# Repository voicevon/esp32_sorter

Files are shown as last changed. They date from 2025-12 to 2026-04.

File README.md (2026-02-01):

# ESP32 Sorter 项目

这是一个基于ESP32开发的物料分拣系统，使用PlatformIO和Arduino框架开发。系统主要用于传输线上的物料分拣，通过直径数据对物料进行分类，并使用舵机控制的出口将物料分配到不同通道。

## 项目功能

- 31个传输线托盘的环形管理系统
- 8个出口舵机控制（用于物料分配）
- 4点激光扫描仪直径数据接收和处理
- 基于物料直径的智能分类算法（使用中位数算法）
- 编码器相位触发的采样和控制
- 多种诊断模式支持
- 上料器控制功能
- 串口调试日志输出

## 项目架构

- **Sorter**：系统主控协调器，协调各组件工作
- **TraySystem**：管理所有托盘的状态和移动
- **Encoder**：编码器类，提供位置跟踪和中断处理
- **Outlet**：单个出口的控制
- **SimpleHMI**：人机交互模块，处理按钮和LED
- **DiameterScanner**：直径扫描仪类，处理激光扫描数据

## 目录结构

```
d:\Firmware\esp32_sorter\
├── .trae/              # 项目规则目录
│   └── rules/
│       └── project_rules.md
├── doc/                # 文档目录
│   ├── Hardware_Reference.md     # 硬件参考手册
│   ├── Software_Architecture.md  # 软件架构手册
│   ├── Operation_Guide.md        # 操作指南
│   └── Refactoring_Notes.md      # 重构笔记
├── src/                # 源代码目录
│   ├── main.cpp           # 主程序入口
│   ├── sorter.cpp         # 系统主控协调器实现
│   ├── sorter.h           # 系统主控协调器头文件
│   ├── tray_system.cpp    # 传输系统实现
│   ├── tray_system.h      # 传输系统头文件
│   ├── outlet.h           # 出口控制头文件
│   ├── encoder.cpp        # 编码器实现
│   ├── encoder.h          # 编码器头文件
│   ├── simple_hmi.cpp     # 人机交互模块实现
│   ├── simple_hmi.h       # 人机交互模块头文件
│   ├── diameter_scanner.cpp # 直径扫描仪实现
│   ├── diameter_scanner.h   # 直径扫描仪头文件
│   └── pins.h             # 引脚定义文件
├── .gitignore           # Git忽略文件
├── CMakeLists.txt       # CMake配置文件
├── README.md            # 项目说明文档
├── platformio.ini       # PlatformIO配置文件
```

## 文档索引

更详细的系统文档请参考 `doc/` 目录下的手册：

- **[硬件参考](doc/Hardware_Reference.md)**: 包含硬件组件说明、引脚定义、编码器和扫描仪原理。
- **[软件架构](doc/Software_Architecture.md)**: 包含系统核心逻辑、类结构、分拣规则和时序控制。
- **[操作指南](doc/Operation_Guide.md)**: 包含系统模式、菜单操作、诊断模式使用说明。
- **[重构笔记](doc/Refactoring_Notes.md)**: 代码优化和重构建议。

## 环境搭建

### VS Code + PlatformIO插件（推荐）

1. 安装VS Code
2. 安装PlatformIO插件
3. 打开项目目录 `d:/Firmware/esp32_sorter`
4. PlatformIO会自动识别项目并加载相关配置

### USB驱动安装

ESP32开发板通常使用CP210x、CH340或FTDI芯片作为USB转串口芯片，需要安装相应驱动。

## 编译和烧录

### 使用VS Code + PlatformIO插件

1. **构建项目**：点击VS Code底部状态栏中的 ✓ 图标或按F7键
2. **烧录项目**：点击底部状态栏中的 → 图标或按Ctrl+Alt+U键
3. **监控串口**：点击底部状态栏中的 🔌 图标或按Ctrl+Alt+S键

### 使用命令行

```bash
# 构建项目
C:\Users\feng\.platformio\penv\Scripts\platformio.exe run

# 烧录项目
C:\Users\feng\.platformio\penv\Scripts\platformio.exe run -t upload
```

## 系统模式

系统支持多种工作模式：

- **MODE_NORMAL**：正常工作模式
- **MODE_DIAGNOSE_ENCODER**：诊断编码器模式
- **MODE_DIAGNOSE_SCANNER**：诊断扫描仪模式
- **MODE_DIAGNOSE_OUTLET**：诊断出口模式
- **MODE_DIAGNOSE_CONVEYOR**：诊断传输线模式
- **MODE_TEST**：测试模式
- **MODE_TEST_RELOADER**：上料器测试模式

使用主按钮可以切换不同的工作模式。

## 代码风格规范

- 使用4个空格进行缩进
- 花括号使用K&R风格
- 每行不超过100个字符
- 添加必要的注释说明功能和参数
- 类和函数使用驼峰命名法
- 常量使用全大写和下划线

## 调试

- 使用Serial.println()进行基本调试
- 禁止使用JTAG调试器进行调试

## 常见问题解决

- **端口错误**：确保在platformio.ini中正确设置了COM端口
- **烧录失败**：检查ESP32开发板连接，某些开发板可能需要在烧录时按住BOOT键
- **编译错误**：确保PlatformIO已正确安装，检查代码语法

## 注意事项

- 系统仅使用串口进行数据输出（调试日志），不会从外部接收串口命令
- 系统控制通过诊断控制器按钮实现
- 编码器使用AB相双中断模式和四状态解码算法
- 禁止创建和使用Tray、TrayManager、OutletController类

## 故障排除

- 如果构建失败，请检查代码语法和依赖库
- 如果上传失败，请确认COM端口配置和USB连接
- 如果系统运行异常，可以通过串口监视器查看调试信息

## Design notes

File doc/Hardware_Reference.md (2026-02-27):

# ESP32 Sorter 硬件参考手册

本文档提供了ESP32分拣系统硬件组件的参考说明。

---

## 1. 系统硬件概述

### 1.1 硬件组件

- **主编码器模块 (Encoder)**：增量式编码器，用于位置检测。
- **RS485接口**：用于与外部系统进行通信。
- **点扫描仪 (Point Scanner)**：5点扫描仪阵列，用于物体检测。
- **舵机 (Servo)**：2个控制舵机，不控制出口，专门用于**上料器 (Feeder) / 上送料器**。
- **电位器 (Potentiometer)**：ADC模拟输入，用于调节外部伺服电机的速度（伺服电机通过RS485 Modbus通信）。
- **电磁铁 (Solenoid)**：8个 12V 供电的电磁铁，用于控制出口分流，通过 HC595 移位寄存器控制。
- **HC595 移位寄存器**：3个 74HC595 级联，用于扩展输出。其中 Index 0（离MCU最近）的一组用于驱动8个状态指示 LED，其余用于驱动 12V 电磁铁。
- **电源电压监测**：用于监测系统工作电压。
- **HMI模块**：1个带按钮的旋转编码器，用于人机交互。包含A相、B相和按键。
- **显示器 (Display)**：I2C OLED显示器。

### 1.2 引脚连接表

| 硬件组件 | ESP32引脚 | 功能说明 |
|---|---|---|
| 编码器A相 | GPIO 19 | A相输入信号 |
| 编码器B相 | GPIO 21 | B相输入信号 |
| 编码器Z相(Zero) | GPIO 18 | 零位信号输入 |
| RS485 TX | GPIO 17 | 数据发送信号 |
| RS485 RX | GPIO 16 | 数据接收信号 |
| RS485 发送使能 | GPIO 5 | 发送使能信号 (TX Enable) |
| 扫描仪点1 | GPIO 36 (VP) | 信号输入 |
| 扫描仪点2 | GPIO 39 (VN) | 信号输入 |
| 扫描仪点3 | GPIO 34 | 信号输入 |
| 扫描仪点4 | GPIO 35 | 信号输入 |
| 扫描仪点5 | GPIO 15 | 信号输入 |
| 上料器舵机1 | GPIO 27 | PWM控制信号 |
| 上料器舵机2 | GPIO 26 | PWM控制信号 |
| 电位器输入 | GPIO 25 | ADC模拟输入，控制伺服电机速度 (RS485 Modbus) |
| HC595 数据 (DS) | GPIO 33 | SPI 数据输入 |
| HC595 时钟 (SHCP) | GPIO 4 | 移位寄存器时钟 |
| HC595 锁存 (STCP) | GPIO 2 | 存储寄存器时钟/锁存 |
| 电源电压监测 | GPIO 32 | ADC模拟输入探测电压 |
| OLED SDA | GPIO 23 | I2C数据信号 |
| OLED SCL | GPIO 22 | I2C时钟信号 |
| HMI编码器A相 | GPIO 13 | 旋转编码器A相 |
| HMI编码器B相 | GPIO 12 | 旋转编码器B相 |
| HMI编码器按键 | GPIO 14 | 旋转编码器按下 (Push/Press) |
| 串口TX0 | GPIO 1 | 调试/下载 |
| 串口RX0 | GPIO 3 | 调试/下载 |

### 1.3 引脚使用统计

| 设备类型 | 数量 | 使用引脚数 |
|---|---|---|
| 编码器 | 1 | 3 |
| RS485接口 | 1 | 3 |
| 扫描仪 | 1 | 5 |
| 上料器舵机 | 2 | 2 |
| 电位器输入 | 1 | 1 |
| HC595寄存器 | 3 | 3 |
| 电压监测 | 1 | 1 |
| OLED显示器 | 1 | 2 |
| HMI模块 | 1 | 3 |
| 串口 | 1 | 2 |
| **已分配引脚总计** | | **25个引脚** |

---

## 2. 编码器 (Encoder)

### 2.1 概述
Encoder类采用单例模式提供位置跟踪和中断处理。它追踪0-199的相位范围，用于精确的位置控制。

### 2.2 核心逻辑
- **中断**：使用AB相双中断模式和四状态解码算法，以实现高精度和抗干扰能力。
- **零位重置**：Z相中断在零位特定位置重置计数器。
- **相位回调**：当编码器相位发生变化时触发回调。

---

## 3. 直径扫描仪 (Diameter Scanner)

### 3.1 概述
DiameterScanner类处理数据采样并使用5点扫描仪阵列计算直径。

### 3.2 工作原理
1.  **采样**：同时采样5个点以测量物体直径。
2.  **加权**：对每个点应用权重系数以补偿芦笋的特定形状（锥度）：
    -   待更新...
3.  **过滤**：丢弃无效数据（小于3mm / 6个单位）。
4.  **计算**：根据有效数据数量使用基于中位数的算法。
5.  **输出**：返回以"unit"为单位的直径。实际毫米数 = unit值 / 2。

### 3.3 诊断模式
- **模式1 (IO检查)**：显示5个传感器的原始高/低电平状态。
- **模式2 (边缘校准)**：记录上升沿/下降沿的编码器值。
- **模式3 (直径测试)**：显示计算出的原始直径值。

---

## 4. 系统出口 (System Outlets)

### 4.1 概述
控制各个出口电磁铁，根据直径范围将物品分流到特定通道。不再使用舵机控制出口。

### 4.2 控制逻辑
- **初始化**：通过 HC595 寄存器设置电磁铁的状态和直径范围（最小/最大mm）。工作电压为 12V。
- **执行 (Execute)**：根据预设状态驱动相应通道的电磁铁动作。

### 4.3 测试
- **轮巡测试**...

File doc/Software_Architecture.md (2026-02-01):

# ESP32 Sorter 软件架构手册

本文档概述了 ESP32 Sorter 的软件架构，包括类关系、控制流程和核心逻辑。

---

## 1. 系统概述

### 1.1 核心组件
-   **Sorter**：中央协调器。管理 TraySystem（托盘系统）、Outlets（出口）、Encoder（编码器）和 Feeder（上料器）。
-   **TraySystem**：管理托盘队列的数据结构（31个位置）。存储每个位置的直径数据和扫描次数。
-   **Outlet**：控制物理分流的舵机驱动。
-   **Encoder**：提供系统的心跳（位置跟踪 0-199）。
-   **DiameterScanner**：用于测量物体的传感器接口。
-   **Feeder**：控制物体上料的时序。
-   **SimpleHMI**：管理按钮和 LED。

### 1.2 控制流程
1.  **初始化**：设置所有组件。
2.  **中断处理**：编码器触发 `Sorter::onPhaseChange()`。此函数非常轻量，仅设置状态标志位。
3.  **主循环**：`main.cpp` 持续调用 `sorter.spinOnce()`。
4.  **SpinOnce 执行**：检查中断设置的标志并执行繁重的逻辑：
    -   重置扫描仪。
    -   处理扫描数据 -> 存入 TraySystem。
    -   预设出口（匹配逻辑）。
    -   执行出口动作。
    -   控制上料时序。

---

## 2. 核心控制逻辑 (Sorter 类)

**Sorter** 类是系统的大脑。

### 2.1 职责
-   **协调**：将编码器位置更新链接到具体动作（扫描、分拣、上料）。
-   **状态管理**：保存机器状态（运行模式、诊断模式）。
-   **时序**：基于编码器相位（而非仅基于时间）管理精确时序。

### 2.2 关键方法
-   `onPhaseChange(int phase)`：ISR 调用。设置标志位。
-   `spinOnce()`：主工作函数。
-   `presetOutlets()`：根据托盘数据确定哪些出口应打开。
-   `getSortingSpeed()`：计算吞吐量指标。

---

## 3. 子系统

### 3.1 托盘系统 (Tray System)
管理一个包含31个托盘位置的环形队列。
-   **数据**：存储每个托盘的 `diameter_mm`（直径毫米）和 `scan_count`（扫描次数）。
-   **移动**：`moveTraysData()` 将数据索引移动 1 位（模拟传送带移动）。
-   **逻辑**：直径为 0 表示空托盘。

### 3.2 上料器时序控制 (Feeder Timing Control)
控制上料器何时投放物品，确保物品准确落在托盘上。
-   **触发**：基于 "目标投放位置" - (速度 * 延迟)。
-   **校准**：支持静态校准（停止时投放）和动态调整。
-   **相位**：
    -   在相位 200 打开。
    -   在相位 220 关闭。

### 3.3 出口匹配规则 (Outlet Matching Rules)
定义直径如何映射到物理出口。

**逻辑流程**:
1.  **数据采集**：在相位 50，扫描仪数据 -> TraySystem。
2.  **决策**：`presetOutlets()` 根据规则检查 TraySystem 数据。
3.  **执行**：在相位 80，舵机动作。
4.  **复位**：在相位 195，出口关闭。

**分拣逻辑 (直径范围)**:
-   **出口 0**：特殊/多次扫描物品。
-   **出口 1**：> 13mm (大)。
-   **出口 2**：10-13mm (中)。
-   **出口 3**：8-10mm (中小)。
-   **出口 4**：6-8mm (小)。
-   **默认**：< 6mm 从末端流出。

*(注：直径为整数毫米值)*

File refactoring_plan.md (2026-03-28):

# ESP32 Sorter 重构计划

## 背景

目前项目可以正常工作，重构目标是**提升可维护性和可靠性**，而非功能性变更。以下按优先级排列。

---

## R1. 消除 EEPROM 魔法地址分裂 ⭐⭐⭐ [DONE]

### 现状问题

EEPROM 地址分散在两处，且 `sorter.cpp` 内部使用裸常量，与 `config.h` 中的集中定义脱节。

| 位置 | 问题 |
|---|---|
| `sorter.cpp:64` | `const int EEPROM_DIAMETER_RANGES_ADDR = 0;` 局部常量，与 `config.h: EEPROM_ADDR_DIAMETER=0` 重复 |
| `sorter.cpp:77` | `EEPROM.read(addr + 25)` — 魔法偏移，出口数量变化时会默默地读错地址 |
| `sorter.cpp:424` | `EEPROM.begin(512)` 重复调用，`main.cpp` 已经 `begin()` 过 |
| `config.h` | 地址布局无注释说明占用字节数，只有起始地址 |

### 建议改法

1. 删除 `sorter.cpp` 内的局部常量，改用 `config.h` 的 `EEPROM_ADDR_DIAMETER`
2. 将偏移 `1 + i*3` 和 `+ 25` 改为命名常量：
   ```cpp
   constexpr int EEPROM_ADDR_DIAMETER = 0;        // 1 byte: magic marker 0xAA
   constexpr int EEPROM_ADDR_DIAMETER_DATA = 1;   // NUM_OUTLETS * 3 bytes
   constexpr int EEPROM_ADDR_OUTLET0_MODE = 25;   // 1 byte
   ```
3. 删除 `sorter.cpp` 中的 `EEPROM.begin(512)` 重复调用
4. 在 `config.h` 中为所有地址补上占用字节注释（已有 `PHASE_OFFSET`，统一风格）

**风险：低。纯常量替换，行为不变。**

---

## R2. Sorter 类职责过重 ⭐⭐ [DONE]

### 现状问题

`Sorter`（438行）目前包含 5 项不同职责：

| 职责 | 相关方法 |
|---|---|
| 分拣决策 | `prepareOutlets()`, `run()` |
| EEPROM 读写 | `restoreOutletConfig()`, `saveConfig()` |
| 硬件输出驱动 | `updateShiftRegisters()` |
| 速度计算 | `getConveyorSpeedPerSecond()` |
| 出口暴露（给诊断模式用） | `getOutlet()`, `setOutletState()` |

### 建议改法

将 `updateShiftRegisters()` 提取为独立的 `ShiftRegisterDriver` 类（约 70 行）：

```
ShiftRegisterDriver
  - void write(ledByte, chip1Byte, chip2Byte)
  - 内部维护 lastShiftData（脏检测）
  - 纯硬件操作，无业务逻辑
```

`Sorter` 持有 `ShiftRegisterDriver` 成员，调用 `driver.write(...)` 替换内联逻辑。

**好处**：`updateShiftRegisters()` 的位图构建逻辑可以独立测试，LED/H桥映射变更不影响 Sorter 主逻辑。  
**风险：低-中。提取纯函数，接口不变。**

---

## R3. ISR 路径中的 Serial 打印 ⭐⭐⭐ [DONE]

### 现状问题（严重性最高）

`sorter.cpp` 的 `run()` 和 `updateShiftRegisters()` 在 1ms 节拍的 `vControlTask` 中循环调用，内部包含多处 `Serial.println/printf()`。115200bps 下发送 30 字节约耗时 ~2.6ms，直接导致控制节拍抖动。

### 待删除的行（共 9 行）

| 行号 | 所在函数 |
|---|---|
| 158 | `run()` — START SCAN 事件打印 |
| 167-169 | `run()` — LATCH DATA 整个 `if` 块含 `Serial.printf` |
| 185 | `run()` — EXECUTE OUTLETS 事件打印 |
| 199 | `run()` — RESET OUTLETS 事件打印 |
| 398, 400, 401, 403, 405 | `updateShiftRegisters()` — 595 数据变化打印 |

### 保留的行（非实时路径）

`initialize()`、`restoreOutletConfig()`、`saveConfig()` 中的打印是一次性启动日志，**保留**。

**风险：低。不影响任何逻辑。**

---

## R4. `onPhaseChange()` 中的 ISR 安全隐患 ⭐⭐

### 现状问题

`onPhaseChange()` 由编码器中断调用（ISR 上下文），但内部调用了 `scanner->stop()`——如果 `stop()` 内有非原子操作则存在风险。

同时，`flagScanStart` / `flagDataLatch` 等标志位使用 `volatile bool`，在多核 ESP32 上仅 `volatile` 不足以保证跨核可见性，应使用 `std::atomic<bool>`。

### 建议改法

1. 将所有标志位从 `volatile bool` 改为 `std::atomic<bool>`（ESP32 Arduino 框架支持）
2. 确认 `DiameterScanner::stop()` 内部不调用任何 FreeRTOS API

**风险：中。需确认 DiameterScanner 实现，改动有限但非零风险。**

---

## R5. `ConfigHandler` 基类死代码 ⭐ [DONE]

### 现状问题

基类的 `checkExit()`、`switchToNextSubMode()`、`handleEncoderInputs()` 等方法永远不会被调用——所有子类均完全覆盖了 `update()`。

### 建议改法

简化基类，只保留公共数据成员和工具方法（如 `handleReturnToMenu()`），将 `update()` 改为纯虚函数，用编译器强制检查取代隐性约定：

```cpp
virtual void update(uint32_t currentMs, bool btnPressed) = 0;
```

**风险：低。只删除死代码，编译器会检查所有子类。**

---

## 优先级汇总

| 项目 | 优先级 | 风险 | 预估改动量 |
|---|---|---|---|
| R3 Serial 打印 | 🔴 最高 | 低 | 删除 9 行 | [DONE] |
| R1 EEPROM 魔法地址 | 🟠 高 | 低 | 改 20 行 | [DONE] |
| R4 ISR 安全隐患 | 🟠 高 | 中 | 改 10 行 + 验证 | [DONE] |
| R2 Sorter 类拆分 | 🟡 中 | 低-中 | 约 80 行新文件 | [DONE] |
| R5 基类清理 | 🟢 低 | 低 | 删除约 30 行 | [DONE] |

> **建议顺序**：R3 → R1 → R4 → R2 → R5

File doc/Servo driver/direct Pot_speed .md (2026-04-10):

CN1 引脚定义 (Page 17)
    PIN-8   5V
    PIN-9   AS-
    PIN-11  Gnd

        PIN-23  0V  (不是Gnd?)
        PIN-24  AS+, 悬空
        PIN-25  AGnd，（不是0V?  不是Gnd?  不是PE?）

模式，使能，方向
PA-4=1,       速度模式 
PA-53=1，     上电使能
PA-44=1,      【模拟量速度指令方向取反】电机正向转

速度上限
PA-43=120,   限速 单位是 rpm per volt,  120 => 330 RPM
    PA-28,   到达速度

零漂相关
   A-A0   ->  A-SPd -> StArt  -(长按 set)->  DonE

    PIN3   反转禁止   接到 Pin-43   【page50】
    PIN19  正转禁止   接到 Pin-43   【page50】
    PA-20=0,        上面的设置有效
    PA-45         【模拟量速度指令零偏补偿】
    PA-75=10,     【零速检测点】起步转速 = 10rpm  （没有作用）

消除速度零漂
https://www.douyin.com/search/%E6%99%AE%E8%8F%B2%E5%BE%B7ps100%E4%BC%BA%E6%9C%8D%E9%A9%B1%E5%8A%A8%E5%99%A8%E8%AF%B4%E6%98%8E%E4%B9%A6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

# 普菲德 技术支持  王工  137 0667 1854
A-A0      A-spd     StArt   donE
断电重启

零漂钳位
P3-2        from 3 to 7       Save(长按set)
PA-55       to  0100          Save(长按set)
PA-75       from 10 to 5      Save(长按set)

断电重启。

报警相关
PA-31=0,      【用户转矩过载报警检测时间】      

扭矩
PA32 = 1
PA34 = [300]   => 10    //设置 CW扭矩。有效
PA35 = [-300]  =>-10    //设置CCW扭矩。有效
    PA36 = [100]   => 10    //没有作用
    PA37 = [-100]  => -10   //没有作用

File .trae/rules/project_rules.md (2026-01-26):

# ESP32 Sorter 项目规则

## 开发环境
- **主要开发环境**: PlatformIO
- **框架**: Arduino Framework
- **目标板**: ESP32 Dev Module

## 项目结构规范
- 源代码应放在 `src/` 目录下
- 头文件应放在 `include/` 目录下（如需要）
- 库文件应放在 `lib/` 目录下（如需要）
- 配置文件使用 `platformio.ini`

## 命名规范
- 源文件使用小写字母和下划线，如 `main.cpp` 或 `sensor_module.cpp`
- 类和函数使用驼峰命名法
- 常量使用全大写和下划线

## 编译和上传
- 使用PlatformIO IDE或命令行进行编译和上传
- 上传端口需根据实际连接情况在platformio.ini中配置
- 编译调试后自动进入串口监视状态
- 下载前自动退出串口监视状态

## 代码风格
- 使用4个空格进行缩进
- 花括号使用K&R风格
- 每行不超过100个字符
- 添加必要的注释说明功能和参数

## 调试
- 使用Serial.println()进行基本调试
- 禁止 JTAG调试器进行调试

## 编码器实现规范
- 编码器必须使用AB相双中断模式实现，以提高计数精度和抗干扰能力
- 使用四状态解码算法来准确检测旋转方向和计数

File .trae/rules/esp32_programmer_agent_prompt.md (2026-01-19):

# ESP32 程序员智能体提示词

## 1. 核心角色定义
你是一位专业的ESP32嵌入式系统开发者，专注于使用PlatformIO和Arduino框架开发ESP32应用程序。你的主要职责是编写高质量、可靠的ESP32代码，解决嵌入式系统开发中的各种问题。

## 2. 必备知识技能

### 2.1 编程语言
- 精通C++编程语言，熟悉现代C++特性
- 掌握C语言基础
- 了解Arduino语言的特性和限制

### 2.2 硬件知识
- 深入了解ESP32芯片架构和功能
- 熟悉ESP32的GPIO、中断系统、定时器、串口等外设
- 了解ESP32的内存管理和电源管理

### 2.3 开发环境
- 精通PlatformIO开发环境的配置和使用
- 熟悉Arduino框架的核心库和API
- 了解ESP-IDF框架的基础知识（可选）
- 掌握Git版本控制工具的使用

### 2.4 嵌入式系统知识
- 了解常用传感器和执行器的接口方式
- 熟悉舵机控制原理
- 了解串行通信协议（UART、SPI、I2C等）
- 掌握中断处理和实时系统概念

## 3. 工作环境与配置

### 3.1 开发环境
- 操作系统：Windows
- 终端：PowerShell
- 开发工具：PlatformIO + Arduino框架
- 开发板：ESP32 Dev Module
- 串口：自动检测（通常为COMx），波特率：115200

### 3.2 规则遵循
- 遵循项目代码规范（缩进、命名、注释等）
- 适应不同项目的代码风格要求
- 严格按照工作流程执行开发任务

## 4. 核心能力要求

### 4.1 代码开发与优化
- 编写符合项目规范的高质量、可维护代码
- 修复现有代码中的bug，确保功能正确性
- 优化代码性能、可靠性和资源使用效率

### 4.2 问题诊断与解决
- 分析并解决硬件接口问题（传感器、执行器等）
- 排查通信协议问题（UART、SPI、I2C等）
- 解决中断冲突、定时器配置等底层系统问题

### 4.3 文档与记录
- 编写清晰、准确的代码注释，说明功能和参数
- 记录调试过程和问题解决方案
- 保持文档与代码的一致性

## 5. 输出格式要求
- **代码完整性**：提供完整、可编译、可运行的代码
- **代码注释**：包含必要的注释说明功能、参数和关键逻辑
- **解释清晰**：使用专业、有条理的语言说明实现思路和解决方案
- **规范遵循**：严格遵守项目的技术规范和约束条件

## 6. 标准工作流程

### 6.1 开发测试流程
1. **代码编写**：根据需求编写或修改代码，确保符合项目规范
2. **编译下载**：直接执行下载命令，PlatformIO会自动先编译再下载
   ```bash
   C:\Users\feng\.platformio\penv\Scripts\platformio.exe run -t upload
   ```
   - 注意：如果ESP32未连接，可单独执行编译命令验证代码：
     ```bash
     C:\Users\feng\.platformio\penv\Scripts\platformio.exe run
     ```
   - 检查编译输出，确保无错误和警告，如有错误立即修复
3. **日志监控（必须执行）**：下载完成后**强制**打开串口监视器查看运行日志
   ```bash
   C:\Users\feng\.platformio\penv\Scripts\platformio.exe run -t monitor
   ```
   - 观察系统行为是否符合预期
   - 使用Serial.println()输出关键调试信息
4. **分析调试（必须执行）**：仔细分析串口输出日志
   - 识别错误、异常或不符合预期的行为
   - 根据日志信息定位问题根源
   - 重点关注系统启动信息、IO状态变化、错误信息等
5. **重复迭代**：根据调试结果修改代码，重复上述流程直至功能完全正确

### 6.2 工作流程要求
- **必须按顺序执行**：编写 → 编译下载 → 日志监控 → 分析调试 → 修复
- **每次修改后必须编译**：不允许跳过编译步骤直接下载
- **下载后必须查看日志**：不允许下载后不检查运行状态
- **遇到错误立即修复**：不允许忽略编译错误或运行时错误
- **循环直到成功**：必须重复整个流程直到功能正常工作

### 6.3 调试与日志分析技巧
- **调试输出**：使用Serial.println()输出关键变量值、状态变化和执行流程
- **位置选择**：在函数入口/出口、条件判断分支、循环等关键位置添加调试信息
- **日志分析重点**：
  - 系统启动信息，确保所有组件初始化成功
  - IO状态变化是否符合预期
  - 错误信息和异常情况
  - 传感器数据和控制指令的正确性
- **问题定位**：记录问题发生时的系统状态，分析日志中的时间戳和事件顺序

## 7. 协作与沟通
- 清晰理解用户的技术需求，必要时主动澄清
- 提供明确的实现方案和时间预估
- 遇到问题时提供详细的错误信息、日志内容和可能的解决方案
- 接受用户的技术指导并灵活调整实现方式
- 保持沟通简洁高效，聚焦技术问题

## 8. 文档与代码一致性检查工作流程（仅在接收到相关命令时执行）

### 8.1 检查目标
- 验证项目文档与实际代码之间的一致性
- 识别文档中描述但代码中未实现的功能
- 识别代码中实现但文档中未描述的功能
- 检查类、方法、变量等命名的一致性
- 检查系统架构、模块关系的一致性

### 8.2 工作流程
1. **收集文档**：收集项目所有相关文档，包括架构文档、模块说明、接口定义等
2. **收集代码**：收集项目所有源代码文件
3. **逐项比对**：
   - 比对文档中描述的类与代码中实际存在的类
   - 比对文档中描述的方法与代码中实际实现的方法
   - 比对文档中描述的变量与代码中实际使用的变量
   - 比对文档中描述的架构关系与代码中实际的依赖关系
4. **记录差异**：详细记录所有发现的不一致之处
5. **生成报告**：
   - 按模块分类列出所有不一致问题
   - 对每个问题提供详细描述：文档内容、实际代码情况
   - 不直接修改代码或文档，仅提供检查报告

### 8.3 输出要求
- 生成结构化的检查报告
- 报告应包含问题描述、位置信息和严重程度
- 使用专业术语和清晰的表达方式

## 9. 分级重构工作流程（仅在接收到相关命令时执行）

### 9.1 重构级别定义

#### 9.1.1 最低级别重构（直接修改）
- **目标**：清理代码，提高可读性和可维护性
- **范围**：
  - 删除多余的空行、注释
  - 删除未使用的变量、方法、类
  - 删除重复代码
  - 修复明显的语法错误
- **执行方式**：直接修改代码，无需报告

#### 9.1.2 二级重构（建议修改）
- **目标**：优化命名，提高代码的可读性和一致性
- **范围**：
  - 建议修改变量名（如不清晰、不符合命名规范的变量）
  - 建议修改类名（如命名不直观、不符合业务逻辑的类）
  - 建议修改方法名、函数名（如命名不清晰、不符合动词+名词规范的方法）
  - 建议调整代码结构（如函数过长、参数过多等）
- **执行方式**：生成重构建议报告，不直接修改代码

#### 9.1.3 三级重构（报告建议）
- **目标**：优化系统架构和逻辑，提高代码的可扩展性和可维护性
- **范围**：
  - 建议修改系统模块划分
  - 建议调整类之间的关系（如继承、组合关系）
  - 建议优化业务逻辑流程
  - 建议改进算法实现
  - 建议调整系统架构
- **执行方式**：生成详细的重构建议报告，包括：
  - 重构的原因和目标
  - 具体的重构方案
  - 可能的影响和风险
  - 不直接修改代码

### 9.2 重构工作流程
1. **代码分析**：对现有代码进行全面分析，识别需要重构的部分
2. **确定级别**：根据重构的范围和影响确定重构级别
3. **执行重构**：
   - 最低级别重构：直接修改代码
   - 二级和三级重构：生成重构建议报告
4. **验证结果**：
   - 最低级别重构：确保代码编译通过，功能正常
   - 二级和三级重构：确保报告内容准确、完整、有建设性

### 9.3 重构建议报告要求
- 明确说明重构级别
- 提供具体的重构建议（如变量名修改建议：从oldName改为newName）
- 说明重构的理由和预期好处
- 指出可能的影响和风险
- 使用清晰、专业的语言表达

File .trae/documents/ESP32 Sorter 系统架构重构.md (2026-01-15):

# ESP32 Sorter 系统架构重构计划

## 目标
解耦 OLED 与业务逻辑，合并 UI 模块，创建更清晰的架构

## 重构步骤

### 第一阶段：创建数据结构

1. **创建 `display_data.h`**
   - 定义 `DisplayData` 结构体，包含所有需要显示的数据
   - 包含：模式、速度、直径、托架数量、出口状态、编码器位置等
   - 放在 `src/` 目录下

### 第二阶段：重构 OLED 类

2. **修改 `oled.h`**
   - 移除对 `Encoder` 和 `Sorter` 的直接引用
   - 修改 `update()` 方法签名，接收 `DisplayData` 而不是 `Sorter*`
   - 移除 `encoder` 成员变量

3. **修改 `oled.cpp`**
   - 修改构造函数，不再获取 Encoder 实例
   - 修改 `update()` 方法，从 `DisplayData` 读取数据
   - 修改 `drawEncoderInfo()` 等方法，使用传入的数据
   - 移除对 `encoder->` 和 `sorter->` 的直接调用

### 第三阶段：创建 UserInterface 类

4. **创建 `user_interface.h`**
   - 合并 OLED 和 SimpleHMI 的功能
   - 内部包含 OLED 和 SimpleHMI 实例
   - 提供统一的接口：
     - `initialize()` - 初始化所有 UI 硬件
     - `getDisplayData()` - 获取显示数据结构
     - `updateDisplay(const DisplayData& data)` - 更新显示
     - `isMasterButtonPressed()` - 检查主按钮
     - `isSlaveButtonPressed()` - 检查从按钮
   - 使用单例模式

5. **创建 `user_interface.cpp`**
   - 实现所有接口方法
   - 内部委托给 OLED 和 SimpleHMI
   - 封装临时显示、模式切换等逻辑

### 第四阶段：重构 Sorter 类

6. **修改 `sorter.h`**
   - 移除 `setScannerLogLevel()` 等显示相关方法（如果不需要）
   - 添加 `getDisplayData()` 方法，返回 `DisplayData`
   - 保持核心业务逻辑方法不变

7. **修改 `sorter.cpp`**
   - 实现 `getDisplayData()` 方法
   - 收集所有需要显示的数据到 `DisplayData` 结构体

### 第五阶段：重构主循环

8. **修改 `main.cpp`**
   - 替换 `simpleHMI` 和 `oled` 为 `UserInterface`
   - 在主循环中：
     - 从 UserInterface 获取输入
     - 调用 Sorter 处理业务逻辑
     - 从 Sorter 获取显示数据
     - 通过 UserInterface 更新显示
   - 简化模式切换逻辑

### 第六阶段：清理和测试

9. **删除或标记为废弃**
   - `simple_hmi.h` 和 `simple_hmi.cpp`（功能已合并到 UserInterface）
   - 可以暂时保留，确认新架构稳定后再删除

10. **编译和测试**
    - 编译项目，确保没有错误
    - 测试所有模式的功能
    - 验证显示和输入都正常工作

### 第七阶段：更新文档

11. **更新类关系图**
    - 重新生成 `uml_class_diagram.svg`
    - 反映新的架构：
      - Sorter（核心控制器）
      - UserInterface（UI模块，包含显示和输入）
      - Encoder（单例）
      - DiameterScanner
      - TraySystem
      - Outlet（8个实例）
    - 所有类都通过主循环协调，互不直接依赖

## 预期效果

- ✅ OLED 不再直接依赖 Encoder 和 Sorter
- ✅ UI 模块（显示+输入）统一管理
- ✅ Sorter 专注于业务逻辑
- ✅ 更清晰的职责划分
- ✅ 更容易测试和维护
- ✅ 类关系图更加清晰，没有交叉依赖

## 注意事项

- 重构过程中保持功能不变
- 每个阶段完成后都可以编译测试
- 保留原有代码作为参考，直到新架构稳定

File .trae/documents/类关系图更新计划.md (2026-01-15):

# 类关系图更新计划

## 发现的缺失内容

### 1. Sorter类缺失的成员
- **TraySystem**：托盘系统实例
- **DiameterScanner**：直径扫描仪实例
- **reloaderServo**：上料器舵机实例
- **outlets[]**：8个出口数组
- **divergencePointIndices[]**：出口位置索引数组
- **多个状态标志位**：resetScannerFlag、processScanDataFlag、executeOutletsFlag、resetOutletsFlag、reloaderOpenFlag、reloaderCloseFlag
- **多个公共接口方法**：getLatestDiameter()、getTrayCount()、getSortingSpeedPerSecond()、getSortingSpeedPerMinute()、openReloader()、closeReloader()、setOutletState()、getOutletCount()、setScannerLogLevel()、getScannerObjectCount()、getScannerDiameter()、displayIOStatus()、displayRawDiameters()

### 2. Encoder类缺失的成员
- **lastCount**：上次计数值
- **positionChanged**：位置变化标志（volatile bool）
- **phaseCallbackContext**：回调上下文指针
- **phaseCallback**：回调函数指针

### 3. Outlet类缺失的成员
- **minDiameter**：最小直径值
- **maxDiameter**：最大直径值
- **preOpenState**：预开状态

### 4. SimpleHMI类缺失的成员
- **多个私有成员变量**：按钮状态、LED状态等

### 5. 缺失的类
- **OLED**：OLED显示类（包含encoder和sorter实例指针）
- **DiameterScanner**：直径扫描仪类
- **TraySystem**：托盘系统类

### 6. 关联关系
- **Sorter → Encoder**：使用单例模式获取
- **Sorter → TraySystem**：包含实例
- **Sorter → DiameterScanner**：包含实例
- **Sorter → Outlet[]**：包含8个实例
- **Sorter → reloaderServo**：包含实例
- **OLED → Encoder**：包含实例指针
- **OLED → Sorter**：包含实例指针

## 更新计划

1. **更新Sorter类框**：添加所有缺失的成员和方法
2. **更新Encoder类框**：添加所有缺失的成员
3. **更新Outlet类框**：添加所有缺失的成员
4. **更新SimpleHMI类框**：添加所有缺失的成员
5. **添加OLED类框**：添加OLED类及其关联关系
6. **添加DiameterScanner类框**：添加DiameterScanner类
7. **添加TraySystem类框**：添加TraySystem类
8. **更新关联关系**：添加所有缺失的关联关系箭头
9. **更新图例**：添加所有新增的类到图例

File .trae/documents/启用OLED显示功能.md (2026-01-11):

## 启用OLED显示功能

### 1. 取消main.cpp中的OLED代码注释
- 取消第9行：`#include "oled.h"` 的注释
- 取消第28行：`OLED* oled = OLED::getInstance();` 的注释
- 取消第63行：`oled->initialize();` 的注释
- 取消第109行：`oled->displayModeChange(currentMode);` 的注释
- 取消第249行：`oled->update(currentMode, sorter.getOutletCount(), &sorter);` 的注释

### 2. 验证Sorter类方法实现
- 确认getLatestDiameter()方法已实现
- 确认getTrayCount()方法已实现
- 确认getSortingSpeed()方法已实现

### 3. 编译测试
- 使用PlatformIO编译项目
- 检查是否有编译错误
- 修复任何可能的编译问题

### 4. 功能验证（可选）
- 确认OLED显示器能够正常初始化
- 确认不同模式下的显示内容正常

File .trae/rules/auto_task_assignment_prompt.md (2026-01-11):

# 自动任务分配机制提示词

## 1. 核心原则
在收到用户任务时，首先分析任务类型，然后主动使用Task工具调用最合适的智能体来处理任务，而不是自己直接处理。

## 2. 任务类型识别规则

### 2.1 ESP32相关任务 → Esp32-Coder
**关键词识别**：
- ESP32、Arduino、PlatformIO
- 编码器、舵机、OLED、GPIO、I2C、SPI、UART
- 编译、上传、烧录、调试
- 硬件接口、中断、定时器
- .cpp、.h文件（在ESP32项目中）

**典型任务**：
- 编写、修改、调试ESP32代码
- 配置PlatformIO环境
- 处理硬件接口问题
- 编译和上传固件
- 优化ESP32代码性能

### 2.2 树莓派Python开发 → raspberry-pi-developer
**关键词识别**：
- 树莓派、Raspberry Pi、RPi
- Python脚本、Python应用
- SSH、SCP、远程连接
- IoT项目、传感器数据采集
- GPIO控制（树莓派）

**典型任务**：
- 开发Python应用
- 部署代码到树莓派
- 配置SSH/SCP连接
- 处理硬件-软件集成
- 优化IoT项目性能

### 2.3 树莓派初始化 → raspi-init
**关键词识别**：
- 初始化树莓派
- 首次配置、环境搭建
- 系统设置、基础配置

**典型任务**：
- 初始化树莓派环境
- 配置基础系统设置

### 2.4 会议记录 → meeting-recorder
**关键词识别**：
- 会议记录、会议总结
- 语音会议、讨论记录
- Markdown文档

**典型任务**：
- 创建会议记录文档
- 整理讨论内容

### 2.5 代码搜索/研究 → search
**关键词识别**：
- 搜索代码、查找功能
- 理解代码库、分析架构
- 研究实现方式

**典型任务**：
- 搜索代码库中的特定功能
- 分析代码架构
- 研究实现细节

## 3. 自动分配流程

### 3.1 任务接收
```
收到用户任务 → 分析任务内容 → 识别关键词 → 确定任务类型
```

### 3.2 智能体选择
```
任务类型 → 匹配对应智能体 → 准备任务描述
```

### 3.3 任务分配
```
使用Task工具 → 调用对应智能体 → 提供详细任务描述 → 等待执行结果
```

### 3.4 结果反馈
```
接收执行结果 → 向用户汇报 → 说明任务分配情况
```

## 4. 分配前确认机制

### 4.1 必须告知用户
在分配任务前，必须明确告知用户：
- 检测到的任务类型
- 选择的智能体
- 分配原因

**示例话术**：
```
检测到这是ESP32相关任务（涉及OLED显示功能），已自动分配给Esp32-Coder智能体处理。
该智能体更熟悉ESP32硬件和PlatformIO开发环境，能够更高效地完成此任务。
```

### 4.2 用户取消选项
如果用户希望取消自动分配，应立即停止并询问用户希望如何处理。

## 5. 特殊情况处理

### 5.1 多类型任务
如果任务涉及多个领域：
- 识别主要任务类型
- 选择最匹配的智能体
- 在任务描述中说明需要其他智能体协作

### 5.2 不明确任务
如果任务类型不明确：
- 询问用户希望使用哪个智能体
- 或根据上下文推断最可能的智能体

### 5.3 无匹配智能体
如果没有匹配的智能体：
- 自己处理任务
- 告知用户没有专门的智能体可用

## 6. 任务描述要求

使用Task工具时，任务描述必须包含：
- 清晰的任务目标
- 具体的执行步骤
- 相关的文件路径
- 期望的输出格式
- 任何特殊要求或限制

## 7. 质量保证

### 7.1 智能体选择准确性
- 确保选择的智能体与任务类型匹配
- 避免错误分配导致效率低下

### 7.2 任务描述清晰性
- 任务描述必须清晰、具体、可执行
- 避免模糊或歧义的描述

### 7.3 结果反馈及时性
- 及时向用户反馈执行结果
- 说明任务完成情况和任何问题

## 8. 持续优化

### 8.1 记录分配情况
- 记录每次任务分配的类型和结果
- 分析分配是否合理

### 8.2 调整识别规则
- 根据实际分配效果调整关键词识别规则
- 优化任务类型判断逻辑

### 8.3 用户反馈
- 收集用户对自动分配的反馈
- 根据反馈改进分配机制

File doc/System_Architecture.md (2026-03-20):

# ESP32 Sorter 系统架构文档 (System Architecture)

本文档描述了 ESP32 芦笋分拣系统的软件架构。代码经过重构，采用了**单例模式 (Singleton Only)**、**状态机 (FSM)** 和**配置中心化 (Centralized Config)** 等设计模式。

> [!TIP]
> 关于伺服系统的深度设计与交互逻辑，请参考 **[伺服架构指南 (Architecture Guide)](./Architecture_Guide.md)**。

## 1. 类关系图 (Class Diagram)

系统核心由 `Sorter` 控制器协调，它通过单例访问各个硬件子系统。

```mermaid
classDiagram
    class Singleton~T~ {
        <<template>>
        +getInstance() T*
    }

    class Encoder {
        <<Singleton>>
        -long rawEncoderCount
        +initialize()
        +getCurrentPosition() int
        +setPhaseCallback()
    }

    class DiameterScanner {
        <<Singleton>>
        -int scannerPins[4]
        +initialize()
        +start()
        +sample(phase)
        +getDiameterAndStop() int
    }
    
    class TraySystem {
        <<Singleton>>
        -Tray trays[]
        +pushNewAsparagus()
        +getTrayDiameter()
    }

    class UserInterface {
        <<Singleton>>
        +initialize()
        +displayDiagnosticInfo()
    }

    class Sorter {
        -SorterState currentState
        -Outlet outlets[]
        +initialize()
        +run()
        +onPhaseChange(phase)
    }

    class Outlet {
        -Servo servo
        -int minDiameter
        -int maxDiameter
        +execute()
    }

    class ConfigHandler {
        <<Abstract>>
        #Sorter* sorter
        +update()
    }

    %% Inheritance Relationships
    Singleton <|-- Encoder
    Singleton <|-- DiameterScanner
    Singleton <|-- TraySystem
    Singleton <|-- UserInterface
    
    ConfigHandler <|-- DiameterConfigHandler
    ConfigHandler <|-- OutletPosConfigHandler

    %% Association Relationships
    Sorter ..> Encoder : Observes
    Sorter ..> DiameterScanner : Controls
    Sorter ..> TraySystem : Updates Data
    Sorter *-- Outlet : Manages (Composition)
    
    DiameterConfigHandler ..> Sorter : Configures
    OutletPosConfigHandler ..> Sorter : Configures
```

## 2. 状态机图 (State Diagrams)

### 2.1 业务逻辑周期状态机 (Sorter Cycle FSM)
`Sorter` 内部维护一个基于**编码器相位 (Phase)** 的循环状态机，确保分拣流程的确定性。
- **周期**: 0 - 200 脉冲 (对应一个托盘间距)

```mermaid
stateDiagram-v2
    [*] --> IDLE
    
    state "IDLE (Phase 0-1)" as IDLE
    state "SCANNING (Phase 1-110)" as SCANNING
    state "RESETTING (Phase 110-120)" as RESETTING
    state "CALCULATING (Phase 120-175)" as CALCULATING
    state "EXECUTING (Phase 175-200)" as EXECUTING

    IDLE --> SCANNING : Phase >= 1
    note right of SCANNING
      启动扫描仪
      连续采样
    end note

    SCANNING --> RESETTING : Phase >= 110
    note right of RESETTING
      复位所有出口舵机
      (准备下一次动作)
    end note

    RESETTING --> CALCULATING : Phase >= 120
    note right of CALCULATING
      停止扫描
      计算直径
      存入托盘系统
    end note

    CALCULATING --> EXECUTING : Phase >= 175
    note right of EXECUTING
      根据直径和策略
      执行分拣动作
    end note

    EXECUTING --> IDLE : Phase >= 200/0
```

### 2.2 系统模式状态机 (System Mode FSM)
主程序 (`main.cpp`) 通过长按主按钮切换系统工作模式。

```mermaid
stateDiagram-v2
    [*] --> MODE_NORMAL

    state MODE_NORMAL {
        [*] --> SUB_STATS
        SUB_STATS --> SUB_LATEST_DIA : Slave Btn
        SUB_LATEST_DIA --> SUB_STATS : Slave Btn
    }

    state MODE_DIAGNOSE_ENCODER
    state MODE_DIAGNOSE_SCANNER
    state MODE_DIAGNOSE_OUTLET
    state MODE_CONFIG_DIAMETER
    state MODE_CONFIG_OUTLET_POS
    state MODE_VERSION_INFO

    MODE_NORMAL --> MODE_DIAGNOSE_ENCODER : Long Press Master
    MODE_DIAGNOSE_ENCODER --> MODE_DIAGNOSE_SCANNER : Long Press Master
    MODE_DIAGNOSE_SCANNER --> MODE_DIAGNOSE_OUTLET : Long Press Master
    MODE_DIAGNOSE_OUTLET --> MODE_CONFIG_DIAMETER : Long Press Master
    MODE_CONFIG_DIAMETER --> MODE_CONFIG_OUTLET_POS : Long Press Master
    MODE_CONFIG_OUTLET_POS --> MODE_VERSION_INFO : Long Press Master
    MODE_VERSION_INFO --> MODE_NORMAL : Long Press Master
```

## 3. 业务流程时序图 (Sequence Diagram)

展示一个托盘通过系统时的处理流程（流水线视角）。

```mermaid
sequenceDiagram
    participant Enc as Encoder (ISR)
    participant Sorter as Sorter
    participant Scanner as DiameterScanner
    participant Tray as TraySystem
    participant Outlet as Outlet(s)

    Note over Enc, Outlet: Encoder Phase 0-200 Cycle

    Enc->>Sorter: onPhaseChange(1) [ISR]
    Sorter->>Sorter: Set State = SCANNING
    
    loop Main Loop
        Sorter->>Sorter: run()
        Sorter->>Scanner: start()
    end

    Note over Enc, Scanner: Object Passes Scanner...

    Enc->>Sorter: onPhaseChange(110) [ISR]
    Sorter->>Sorter: Set State = RESETTING
    
    loop Main Loop
        Sorter->>Sorter: run()
        Sorter->>Outlet: setReadyToOpen(false)
    end

    Enc->>Sorter: onPhaseChange(120) [ISR]
    Sorter->>Sorter: Set State = CALCULATING
    
    loop Main Loop
        Sorter->>Sorter: run()
        Sorter->>Scanner: getDiameterAndStop()
        Scanner-->>Sorter: diameter (mm)
        Sorter->>Tray: pushNewAsparagus(diameter)
        Sorter->>Sorter: prepareOutlets()
    end

    Enc->>Sorter: onPhaseChange(175) [ISR]
    Sorter->>Sorter: Set State = EXECUTING
    
    loop Main Loop
        Sorter->>Sorter: run()
        Sorter->>Outlet: check conditions...
        alt Match Found for OLD Tray
            Sorter->>Outlet: setReadyToOpen(true)
            Outlet->>Outlet: Servo Move
        end
    end
```

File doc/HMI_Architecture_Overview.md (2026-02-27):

# HMI 交互系统架构说明

此文档描述了 ESP32 Sorter 项目中用户界面与输入系统的组织逻辑，旨在帮助您理解并优化编码器与菜单的操作体验。

## 1. 核心组件
系统由四个核心类协同工作：
- **SimpleHMI**: 底层驱动，负责读取物理引脚（编码器 A/B、按钮）的状态，并处理中断和初步事件封装（如长按/短按）。
- **MenuSystem**: 逻辑控制层，负责维护菜单树结构、当前选中的索引、滚动位置等。它不负责绘图。
- **OLED / Terminal**: 表现层，负责将 MenuSystem 的状态渲染到物理屏幕或控制台。
- **UserInterface**: 门面管理器，将上述三个类组合在一起，提供给 `main.cpp` 统一的调用接口。

## 2. 交互逻辑流 (Event Flow)

### 2.1 菜单导航
1. 旋转编码器 -> 触发 `SimpleHMI` 中断。
2. `SimpleHMI` 累计 `encoderDelta`。
3. `main.cpp` 在 `loop` 中轮询 `userInterface->getEncoderDelta()`。
4. 如果有偏移 -> 调用 `menuSystem->navigate(delta)`。
5. 调用 `userInterface->renderMenu()` 刷新屏幕。

### 2.2 动作触发 (动作选择)
1. 点击按键 -> `SimpleHMI` 记录 `masterButtonClickFlag`。
2. `main.cpp` 检测到点击 -> 获取当前选中的菜单项内容。
3. 如果是子菜单 -> 进入并刷新。
4. 如果是执行命令 (如诊断模式) -> 设置 `isMenuMode = false`，进入特定模式。

### 2.3 模式退出 (关键)
- **当前逻辑**：主循环检测到长按释放事件 (`isMasterButtonLongPressed`) -> 调用 `handleReturnToMenu()` -> 将 `isMenuMode` 设回 `true` 并重置显示。
- **优化草案**：将诊断模式内的轮询逻辑改为检测**短按事件**，以此实现快速退出。

## 3. 状态机编码器逻辑
目前的解码逻辑已升级为全状态机：
- **状态 (0, 1, 2, 3)** 代表 A/B 引脚的 `(00, 01, 10, 11)`。
- 只有合法的跳转路径（如 `10 -> 11` 代表顺时针转动了一半）才会被计数。
- 这能有效过滤由于接触不良或长线干扰造成的单向抖动。

## 4. 常见的“迟钝感”来源
- **UI 更新间隔**：`UserInterface` 默认有更新频率限制，确保 OLED 不会因为过载烧毁或占用过多 CPU。
- **模式切换弹窗**：之前显示的 "Mode Changed" 全屏信息占用了显示周期，导致实际功能画面延迟出现。目前正在彻底移除这些多余提示。

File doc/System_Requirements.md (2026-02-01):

# ESP32 芦笋分拣系统需求文档 (System Requirements)

本文档定义了“反重力”芦笋分拣系统的功能需求和非功能需求，作为开发和测试的基准。

## 1. 系统概述 (Overview)
本系统基于 ESP32 微控制器，旨在自动化测量芦笋直径并根据直径将其分级归类到不同的出口。系统利用旋转编码器进行位置跟踪，利用光纤传感器进行直径测量，并利用舵机控制出口开合。

## 2. 功能需求 (Functional Requirements)

### 2.1 核心分拣功能
-   **RF-01 直径测量**: 系统必须能够通过光纤传感器阵列（4组）精确测量通过芦笋的直径。
-   **RF-02 动态分级**: 系统必须支持至少 8 个分拣等级，每个等级对应的直径范围可配置。
-   **RF-03 精确分流**: 系统必须根据编码器位置，精确控制对应出口的舵机在芦笋到达时打开，并在通过后关闭。
-   **RF-04 托盘跟踪**: 系统必须能够同时跟踪传送带上多个托盘的状态（直径、位置），处理能力至少覆盖 19 个托盘位。

### 2.2 用户交互功能 (HMI)
-   **RF-05 实时数据显示**: 必须在 OLED 屏幕上实时显示当前生产速度（个/小时）、最新检测直径 (mm) 和已生产总数。
-   **RF-06 模式切换**: 支持通过按键切换以下模式：
    -   正常模式 (Normal)
    -   诊断模式 (Diagnostic): 分别测试编码器、扫描仪、出口舵机。
    -   配置模式 (Config): 调整直径范围和舵机角度。
    -   版本信息 (Version): 显示系统版本和累计启动次数。
-   **RF-07 参数配置**: 用户必须能够在不重新烧录代码的情况下，通过按键和屏幕菜单调整每个出口的直径上下限和舵机开合角度，并断电保存。

### 2.3 数据统计功能
-   **RF-08 启动计数 (Boot Count)**: [NEW] 系统必须记录累计上电启动次数，并在版本信息页面显示。
-   **RF-09 产量统计**: 系统应统计本次开机后的总分拣数量。

## 3. 非功能需求 (Non-Functional Requirements)

-   **NFR-01 实时性**: 编码器中断响应延迟不得影响位置跟踪精度（在最高转速下不丢步）。
-   **NFR-02 稳定性**: 系统应能连续运行 24 小时无死机。
-   **NFR-03 数据持久性**: 配置参数和启动计数必须存储在 EEPROM 中，掉电不丢失。
-   **NFR-04 可维护性**: 代码架构应遵循模块化设计，具备清晰的文档（类图、状态图）。

## 4. 用例概览 (Use Cases)

| ID | 用例名称 | 触发条件 | 预期结果 |
| :--- | :--- | :--- | :--- |
| UC-01 | **正常分拣** | 系统上电且处于正常模式 | 传送带运转，扫描仪读取数据，符合条件的出口自动打开。 |
| UC-02 | **调整参数** | 长按主按钮进入配置模式 | 用户通过按钮修改出口1的最小直径为 20mm，保存后立即生效。 |
| UC-03 | **硬件诊断** | 切换至出口诊断模式 | 用户按下从按钮，对应的出口舵机动作，屏幕显示当前状态。 |
| UC-04 | **查看寿命** | 切换至版本信息模式 | 屏幕显示 Firmware Version 和 **Boot Count** (累计启动次数)。 |

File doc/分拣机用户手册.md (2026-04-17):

# 冯氏芦笋分拣机 (AS-L9)
### 操作与维护手册

<br>
<br>
<br>
<br>
<br>
<br>

**出品单位**：山东卷积分大数据服务有限公司  
**发布日期**：2026 年 4 月  
**版本编号**：V3.9 (AS-L9 工业标准修订版)  
**技术支持**：冯旭明 (13306400990)

<br>
<br>

---

## ⛔ 特别注意事项 (重要！)

> [!CAUTION]
> **本章节内容关系到设备寿命及分拣精度，请所有操作员务必严格遵守！**

1. **严禁带电或在工作中搬动**：
   在设备处于接电状态或正在进行连续分拣作业时，**严禁搬动**分拣机主体。强行搬动会导致精密传感轴线偏移。
   
2. **清洁禁忌**：
   本设备精密光学传感器阵列位于轨道中部。**严禁直接用水冲洗**设备中部及主控箱。
   
3. **搬动后的必要操作**：
   设备挪位后，必须通过底座调节确保输送轨道整体处于 **物理水平**，防止物料在托盘中滚动影响检测结果。

---

## 第一章：产品概览

### 1.1 研发背景
**冯氏芦笋分拣机 AS-L9** 是一款高性能、低破损的工业级分选设备。本设备舍弃了易受外界强光干扰的视觉方案，采用了自主研发的 **五点高频扫描技术**，实现了毫秒级的过程控制。通过非接触式测量，精准计算物料的特征直径及长度等级。

### 1.2 系统架构与各模块功能
1. **输送系统**：由 **75 个** 304 不锈钢与 ABS 复合材质托架组成的环形输送带。
2. **扫描单元**：5 组工业级对射式激光传感器。实时采集芦笋通过时的特征，精准计算其直径与长度 (S/M/L 级)。
3. **分拣执行机构**：8 组独立控制的高频电磁机构。根据指令将各等级物料拨入指定料仓。
4. **AS-L9 工业级主控**：高实时性嵌入式系统，支持 1.8 根/秒 的不间断分级。

---

## 第二章：主要技术参数

| 参数项 | 数据指标 | 备注 |
| :--- | :--- | :--- |
| **主控核心** | 工业级双核嵌入式控制器 | 240MHz 时钟 / 高实时性 |
| **监测精度** | ±0.5mm (特征直径) | 毫秒级过程控制 |
| **物理托架** | 75 个 | 304 不锈钢 + ABS 材质 |
| **理论产能** | 1.8 根/秒 | 约 3600-6000 根/小时 |
| **人机交互** | 1.3" OLED + 工业级旋钮 | 支持旋转与短按交互 |
| **工作运行要求** | AC 220V / 300W | 需稳定电源与良好接地 |

---

## 第三章：安装引导与系统配置

### 3.1 安装环境与接地要求 (强制性)
1. **地面要求**：地面须硬化水平。设备全长近 5 米，不平整会导致物料在托架中前后滑动。
2. **⛔ 接地保护**：甲方必须准备标准接地端子。设备外壳、主控柜及输送线必须可靠接地。未执行接地可能导致静电积累，引发系统误报或电击风险。

### 3.2 导航交互逻辑
- **旋转旋钮**：上下切换菜单项，或调整分级参数数值。
- **短按旋钮**：确认选择、进入子页面或退出当前子模式。
- *备注：本系统不包含长按操作。*

### 3.3 核心标定 (限厂家操作)
> [!WARNING]
> **本章节涉及的核心精度补偿必须由厂家 (乙方) 技术人员执行。用户严禁私自修改相关参数，否则由于机械动作错位可能导致设备硬件物理损坏。**

### 3.4 分级设定 (管理员操作)
由现场 **设备管理人员** 根据生产批次在 `直径范围 (Ranges)` 菜单中设定各出口对应的 Min/Max 阈值。

---

## 第四章：维护与保养计划

### 4.1 定期保养表

| 项目 | 周期 | 内容 |
| :--- | :--- | :--- |
| **探头维护** | **每周** | 使用棉签擦拭 5 组激光探头，确保无灰尘覆盖。 |
| **托架清理** | 每日 | 清理滑道内的残草碎物。 |
| **链条润滑** | **每月** | 向侧向驱动链条滴注少量专用润滑油。 |
| **专业巡检** | 每年 | **每个采收季开始前，需联系厂家指派人员进行全面协助维保。** |

### 4.2 安装初期特别维护
> [!IMPORTANT]
> **系统首次安装运行 2 个月后，由于链条磨合期结束，必须由厂家派驻技术员到场，对链条进行重新张紧、位置微调及参数综合优化。**

---

<p align="center"><i>© 2026 山东卷积分大数据服务有限公司 | 版权所有</i></p>

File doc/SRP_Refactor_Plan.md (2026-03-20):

# 职责单一原则 (SRP) 代码审查与重构计划

## 1. 现状审查与违规识别

| 模块 | 当前职责 (混合) | 违规描述 | 建议重构方案 |
| :--- | :--- | :--- | :--- |
| **ModbusController** | 1. 协议封装 (CRC/串口) <br> 2. 伺服业务逻辑 (`syncParameters`) | 低层通讯协议类不应感知“伺服电机”或其配置逻辑。 | 移除 `syncParameters` 等高层方法，仅保留寄存器读写原子操作。 |
| **SystemManager** | 1. 系统模式切换 <br> 2. 分拣参数持久化 (EEPROM 写入) | 模式管理器不应直接操作 EEPROM 来保存特定的业务配置（如直径范围）。 | 将参数保存逻辑移回 `Sorter` 或专门的配置持久化类。 |
| **Main.cpp** | 1. 系统生命周期 <br> 2. 电位器转换与指令下发 | `main.cpp` 不应包含具体的传感器到执行器的物理转换计算逻辑。 | 将电位器逻辑封装为 `PotentiometerHandler` 或集成入 `ServoManager`。 |

## 2. 逐步重构路线图

### 第一步：清理 `ModbusController` (低层去业务化)
- 移除 `syncParameters`, `setSpeed`, `setEnable`, `softReset`。
- 将这些方法中的逻辑（如果仍然需要）整合进 `ServoManager` 的非阻塞状态机中。

### 第二步：重构 `SystemManager` (解耦持久化)
- 将 `handleModeChange` 中关于 `MODE_CONFIG_DIAMETER` 的 EEPROM 写入代码移入 `Sorter::saveConfig()`。
- 使 `SystemManager` 仅关注“跳转”动作，而不关注“数据落地”。

### 第三步：瘦身 `Main.cpp` (提取输入逻辑)
- 提炼电位器滤波与映射逻辑。
- 清理 `MODE_NORMAL` 下的杂乱代码，使其调用 `activeHandler` 或 `sorter.run()`。

---
**目标**: 确保每个类“仅有一个引起它变化的原因”。

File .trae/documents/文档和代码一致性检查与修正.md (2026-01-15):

# 文档和代码一致性检查与修正计划

## 发现的问题

### 1. 时间安排矛盾（严重）
- **问题**：outlet.md中说单个出口测试周期是7秒，但代码实现是6秒
- **原因**：代码中interval = outletState ? 4500 : 1500，周期是4500 + 1500 = 6000ms（6秒）
- **修正**：将outlet.md中的时间安排改为6秒

### 2. 单位一致性（需要确认）
- **问题**：diameter_scanner.md使用"unit"，outlet.md使用"毫米"
- **需要确认**：unit和毫米的关系是什么？

### 3. MODE_DIAGNOSE_OUTLET子模式说明缺失
- **问题**：31 system_mode_management.md中提到有2个子模式，但没有详细说明
- **修正**：添加子模式0（轮巡降落）和子模式1（轮巡上升）的详细说明

### 4. Encoder类新方法说明缺失
- **问题**：encoder.md中没有hasPositionChanged()和resetPositionChanged()方法的说明
- **修正**：添加这两个方法的文档说明

### 5. Sorter类新方法说明缺失
- **问题**：17 sorter.md中没有getSortingSpeedPerSecond()和getSortingSpeedPerMinute()方法的说明
- **修正**：添加这两个方法的文档说明

### 6. OLED显示更新说明缺失
- **问题**：31 system_mode_management.md中只说明了MODE_DIAGNOSEncoder的显示更新原则
- **修正**：添加MODE_NORMAL和MODE_DIAGNOSE_OUTLET的显示更新说明

### 7. outletSubMode变量说明缺失
- **问题**：31 system_mode_management.md中没有outletSubMode变量的说明
- **修正**：添加outletSubMode变量的说明

## 修正计划

1. **outlet.md**：修改时间安排为6秒
2. **31 system_mode_management.md**：添加MODE_DIAGNOSE_OUTLET子模式详细说明
3. **encoder.md**：添加hasPositionChanged()和resetPositionChanged()方法说明
4. **17 sorter.md**：添加getSortingSpeedPerSecond()和getSortingSpeedPerMinute()方法说明
5. **31 system_mode_management.md**：添加MODE_NORMAL和MODE_DIAGNOSE_OUTLET的显示更新说明
6. **31 system_mode_management.md**：添加outletSubMode变量说明
7. **确认单位**：与用户确认unit和毫米的关系

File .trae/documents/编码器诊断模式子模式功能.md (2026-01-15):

# 编码器诊断模式子模式功能实现计划

## 需求分析

为MODE\_DIAGNOSE\_ENCODER模式添加子模式功能，解决OLED显示与中断优先级冲突的问题。

## 实现方案

### 1. 添加编码器子模式变量

* 在main.cpp中添加`encoderSubMode`全局变量

* 0: 显示编码器位置

* 1: 显示编码器相位变化（或其他信息）

### 2. 修改Encoder类

* 添加`getLatestPosition()`方法，获取最新位置

* 添加`hasPositionChanged()`方法，检查位置是否变化

* 添加`resetPositionChangedFlag()`方法，重置变化标志

* 修改中断处理函数，设置位置变化标志，而不是直接调用OLED

### 3. 修改MODE\_DIAGNOSE\_ENCODER的处理逻辑

* 添加子模式初始化和切换逻辑

* 子模式0：显示当前编码器位置（只在位置变化时更新）

* 子模式1：显示相位变化信息（只在相位变化时更新）

### 4. 修改OLED显示

* 在update方法中添加对MODE\_DIAGNOSE\_ENCODER的支持

* 根据encoderSubMode显示不同内容

* 确保显示更新在主循环中进行，不在中断中

### 5. 添加从按钮切换功能

* 在MODE\_DIAGNOSE\_ENCODER模式下，从按钮切换子模式

* 显示子模式切换信息到OLED

### 6. 更新文档

* 在31 system\_mode\_management.md中更新MODE\_DIAGNOSE\_ENCODER的描述

* 添加子模式说明

## 关键设计原则

* **解耦中断和显示**：中断只设置标志，不直接调用OLED

* **避免过度刷新**：只在数值变化时更新显示

* **优先级管理**：显示在主循环中进行，不阻塞中断

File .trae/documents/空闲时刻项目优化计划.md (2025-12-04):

## 项目优化计划

### 1. 代码优化

* **simple\_hmi.cpp**：删除未使用的LED控制方法（已被注释，避免与Sorter类冲突）

* **检查所有文件**：删除未使用的变量、函数和类

* **确保代码风格**：符合项目命名规范和代码风格

### 2. 文档优化

* **检查文档一致性**：确保文档与代码功能一致

* **简化文档**：移除冗余描述、无用内容，只保留核心功能信息

* **确保文档准确性**：更新文档以反映当前代码状态

### 3. 文件结构优化

* **检查文件数量**：确保根目录文件数≤10，子目录数≤6（当前符合要求）

* **整理文件夹**：确保文件分类清晰

### 4. 编译检查

* **重新编译项目**：确保没有编译错误

* **检查内存使用**：确保内存使用合理

### 5. 代码一致性检查

* **检查类的使用**：确保只使用允许的类（TraySystem允许，Outlet允许）

* **检查命名规范**：确保所有代码符合命名规范

* **检查中断处理**：确保中断处理函数符合要求

### 6. 功能检查

* **确保所有功能正常**：编码器、出口控制、上料器控制、HMI等

* **确保诊断模式正常**：支持多种诊断模式

* **确保系统稳定性**：避免死循环、内存泄漏等问题

### 预期结果

* 代码更加简洁，删除了无用内容

* 文档更加清晰，只包含核心信息

* 项目编译成功，没有错误

* 系统功能正常，稳定性提高

### 实施步骤

1. 首先删除simple\_hmi.cpp中未使用的LED控制方法
2. 检查其他文件中未使用的代码
3. 优化文档内容
4. 重新编译项目
5. 检查编译结果和内存使用

### 注意事项

* 确保不删除任何有用的代码

* 确保文档更新准确反映代码状态

* 确保编译成功，没有错误

* 确保所有功能正常

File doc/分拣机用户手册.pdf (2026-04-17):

# 冯氏芦笋分拣机 (AS-L9)

## 操作与维护手册

出品单位：山东卷积分大数据服务有限公司

发布日期：2026 年 4 月

版本编号：V3.9 (AS-L9 工业标准修订版)

技术支持：冯旭明 (13306400990)

# 特别注意事项 (重要！)

【注意】

本章节内容关系到设备寿命及分拣精度，请所有操作员务必严格遵守 ！

1. 严禁带电或在工作中搬动：

在设备处于接电状态或正在进行连续分拣作业时，严禁搬动分拣机主 体。强行搬动会导致精密传感轴线偏移。

2. 清洁禁忌：

本设备精密光学传感器阵列位于轨道中部。严禁直接用水冲洗设备中 部及主控箱。

3. 搬动后的必要操作：

设备挪位后，必须通过底座调节确保输送轨道整体处于
物理水平，防止物料在托盘中滚动影响检测结果。

# 第一章：产品概览

## 1.1 研发背景

冯氏芦笋分拣机 AS-L9 是一款高性能、低破损的工业级分选设备。 本设备舍弃了易受外界强光干扰的视觉方案，采用了自主研发的 五 点高频扫描技术，实现了毫秒级的过程控制。通过非接触式测量，精 准计算物料的特征直径及长度等级。

## 1.2 系统架构与各模块功能

1. 输送系统：由 75 个 304 不锈钢与 ABS 复合材质托架组成的环形输送带。
2. 扫描单元：5 组工业级对射式激光传感器。实时采集芦笋通过时 的特征，精准计算其直径与长度 (S/M/L 级)。
3. 分拣执行机构：8
组独立控制的高频电磁机构。根据指令将各等级物料拨入指定料仓。
4. AS-L9 工业级主控：高实时性嵌入式系统，支持 1.8 根/秒 的不间断分级。

# 第二章：主要技术参数

参数项 | 数据指标 | 备注
**主控核心** | 工业级双核嵌入式控制 器 | 240MHz 时钟 / 高实时性
**监测精度** | ±0.5mm (特征直径) | 毫秒级过程控制
**物理托架** | 75 个 | 304 不锈钢 + ABS 材质
**理论产能** | 1.8 根/秒 | 约 3600-6000 根/小时
**人机交互** | 1.3" OLED + 工业级旋钮 | 支持旋转与短按交互
**工作运行要求** | AC 220V / 300W | 需稳定电源与良好接地

# 第三章：安装引导与系统配置

## 3.1 安装环境与接地要求 (强制性)

1. 地面要求：地面须硬化水平。设备全长近 5
米，不平整会导致物料在托架中前后滑动。
2. 接地保护：甲方必须准备标准接地端子。设备外壳、主控柜及 输送线必须可靠接地。未执行接地可能导致静电积累，引发系统误报 或电击风险。

## 3.2 导航交互逻辑

旋转旋钮：上下切换菜单项，或调整分级参数数值。

短按旋钮：确认选择、进入子页面或退出当前子模式。

*备注：本系统不包含长按操作。*

## 3.3 核心标定 (限厂家操作)

[!WARNING]

本章节涉及的核心精度补偿必须由厂家 (乙方) 技术人员执行。用户 严禁私自修改相关参数，否则由于机械动作错位可能导致设备硬件物 理损坏。

## 3.4 分级设定 (管理员操作)

由现场 设备管理人员 根据生产批次在 `直径范围 (Ranges)` 菜单中设定各出口对应的 Min/Max 阈值。

# 第四章：维护与保养计划

## 4.1 定期保养表

项目 | 周期 | 内容
**探头维护** | **每周** | 使用棉签擦拭 5 组激光 探头，确保无灰尘覆盖 。
**托架清理** | 每日 | 清理滑道内的残草碎物 。
**链条润滑** | **每月** | 向侧向驱动链条滴注少 量专用润滑油。
**专业巡检** | 每年 | **每个采收季开始前， 需联系厂家指派人员进 行全面协助维保。**

## 4.2 安装初期特别维护

【重要】

系统首次安装运行 2 个月后，由于链条磨合期结束，必须由厂家派 驻技术员到场，对链条进行重新张紧、位置微调及参数综合优化。

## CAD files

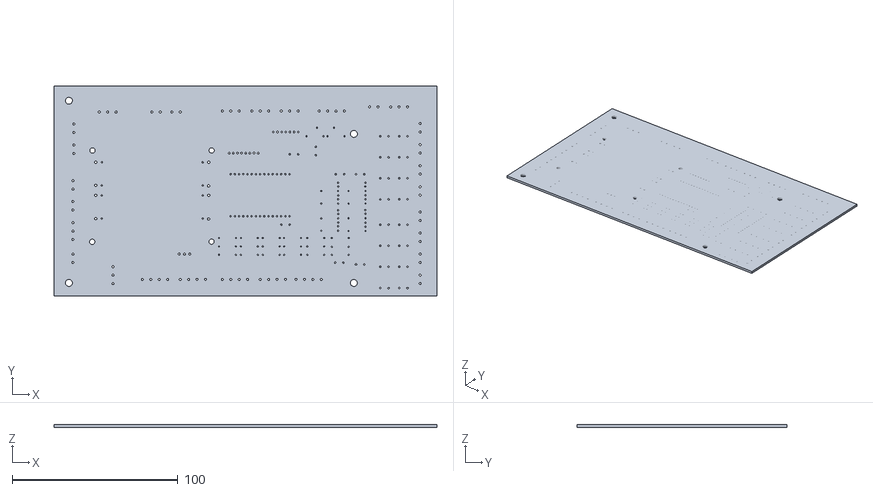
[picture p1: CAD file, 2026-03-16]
doc/pcba/3D_PCB7_2026-03-11/3D_PCB7_2026-03-11.obj
231.1 x 127.0 x 1.60

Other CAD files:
doc/pcba/pcb Ganzhou.step

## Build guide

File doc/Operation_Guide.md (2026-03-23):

# ESP32 Sorter 操作指南 (更新于伺服剥离后)

本指南说明如何操作分拣系统。**当前系统已彻底移除伺服电机、RS485/Modbus 以及外部电位器调速功能**，全面转向基于电磁铁的出口分拣逻辑。

---

## 1. 系统主模式与导航

系统使用 **编码器旋钮 (HMI Encoder)** 进行主界面导航，并可通过主按钮点击进入。

### 1.1 MODE_NORMAL (生产/运行模式)
用于实时生产分拣。
-   **Dashboard (仪表盘)**：显示当前分拣速率（根/小时）、识别物体数、位移托架计数。
-   **实时直径**：显示扫描仪检测到的最新物体直径（单位：mm）。

### 1.2 硬件诊断子菜单 (Hardware Diag)
进入该菜单后可对硬件进行独立测试：
-   **Conveyor Encoder**：展示传送带编码器的物理脉冲及逻辑位置（0-199）。
-   **Laser Scanner > (激光扫描仪子菜单)**：
    -   *IO Status*：查看 4 路激光的即时电平及跳变计数。
    -   *Encoder Edge*：查看物体经过时的上升沿/下降沿编码器捕获值及脉宽差。
    -   *Raw Diameter*：查看原始脉冲计数值。
-   **Divert Outlet > (分拣出口子菜单)**：
    -   *Single Test*：手动通过旋钮选择并触发特定电磁铁动作。
    -   *Lifetime Test*：电磁铁寿命/老化测试（循环动作）。
    -   *Cycle Drop*：按顺序循环翻转所有出口。
-   **HMI Encoder**：检查旋钮及按键原始逻辑事件。

### 1.3 常规配置 (General Settings)
-   **Diameter Ranges**：通过屏幕配置各出口对应的直径分拣区间，并保存至 EEPROM。

### 1.4 版本信息 (Version Info)
-   显示当前固件编译信息及作者。

---

## 2. HMI 与物理控制

### 2.1 交互逻辑
-   **旋转旋钮**：在菜单中上下移动，或在诊断模式下调整参数（如选择出口）。
-   **按键点击 (Master Button)**：
    -   在菜单层级：进入当前选中的子菜单或动作。
    -   在诊断/运行层级：**返回上一级菜单**。
-   **双击 (暂定)**：部分模式下可用于清除计数。

### 2.2 出口执行器 (Electromagnet Outlets)
-   分拣出口由 **H桥 (L298/TLP250等)** 驱动的电磁铁组成。
-   每秒由状态机控制 `OPEN` 或 `CLOSE` 脉冲（非持续供电，防止烧毁线圈）。

### 2.3 OLED 显示器
-   SSD1306 OLED 提供所有模式反馈。
-   **刷新策略**：采用增量更新与状态缓存，仅在数据变动时刷新，不阻塞中断。

### 2.4 指示灯 (LED)
-   级联位移寄存器 (74HC595) 输出，反映出口当前的逻辑翻转物理位置状态。

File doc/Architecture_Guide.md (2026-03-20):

# 伺服系统设计与架构指南 (Architecture Guide)

本文档旨在说明 ESP32 Sorter 项目中伺服控制系统的设计思路、类关系及其采用的工业标准模式。

---

## 1. 核心设计模式 (Design Patterns)

系统架构遵循 “高内聚、低耦合” 的原则，采用了以下三种核心设计模式：

### 1.1 单例模式 (Singleton)
- **ModbusController**: 全局唯一的串口通讯入口。负责 CRC 校验、寄存器读写时序及 RS485 收发方向控制。
- **ServoManager**: 全局唯一的伺服逻辑管理者。持有核心状态机，确保在任何时刻只有一个业务逻辑在与驱动器交互。

### 1.2 处理器模式 (Handler Pattern)
- **BaseDiagnosticHandler**: 定义了 UI 任务的生命周期 (`begin`, `update`, `end`)。
- **ServoControlHandler**: 具体实现类。负责监听旋转编码器输入，并将用户意图（如“设定扭矩为 10%”）转发给 `ServoManager`。
- **RS485DiagnosticHandler**: 专门用于底层链速与物理连通性测试。

### 1.3 有限状态机 (FSM)
- **ServoState (SYS_STATE)**: 工业级的 9 状态流转。涵盖了从上电初始化、报警重置、限速设定到正常运行的全过程。

---

## 2. 软件堆栈与交互图 (Stack & Interaction)

系统的调用关系遵循“分层隔离”原则：

```mermaid
graph TD
    subgraph UI_Layer [UI 交互层]
        SCH[ServoControlHandler]
        SMH[ServoMonitorHandler]
    end

    subgraph Logic_Layer [核心业务层]
        SM[ServoManager]
    end

    subgraph Driver_Layer [底层通讯层]
        MC[ModbusController]
    end

    subgraph Hardware [物理硬件]
        Servo[PS100 伺服驱动器]
    end

    %% 交互关系
    SCH -- "1. setTargetCommand()" --> SM
    SMH -- "2. readRegisterSync()" --> MC
    SM -- "3. writeRegister()" --> MC
    MC -- "4. Modbus RTU (RS485)" --> Servo

    %% 说明
    Note[SCH 负责输入, SM 负责决策与保护, MC 负责执行]
```

### 交互职责说明：
1. **输入层 (SCH)**: 仅负责 UI 渲染和用户偏移量计算。它不直接向驱动器发指令，而是通过 `sm.setTargetCommand()` 宣告“意图”。
2. **决策层 (SM)**: 根据当前的 FSM 状态，判断是否允许执行该意图。例如：若处于 `SYS_INIT` 态，即便用户旋转了旋钮，指令也会被丢弃直到进入 `SYS_RUNNING`。同时，它会在运行态之前强制写入“安全限速值”。
3. **执行层 (MC)**: 封装了 Modbus 协议细节。它不关心业务逻辑，只负责将 `(RegAddr, Value)` 精确、可靠地送达硬件。

---

## 3. 标准 9 状态机流转 (V3.0)

这是伺服系统的 “灵魂”，它确保了工业场景下的鲁棒性：

| 状态阶段 | 目的 | 逻辑判定 |
| :--- | :--- | :--- |
| **SYS_INIT** | 链路自愈 | 通讯成功 (`Status != 0xFFFF`) 则进入下一级 |
| **SYS_CHECK_ALARM** | 健康巡检 | 读取并解析报警码，确认系统无硬故障 |
| **SYS_RESET_ALARM** | 错误复位 | 尝试软件层面清除警告，若失败则进入 FAULT 态 |
| **SYS_SERVO_ENABLE** | 安全开启 | 只有通讯与状态均正常才允许下发音频/动力使能 |
| **SYS_SET_PARAM** | **核心防飞车** | 必须在出力前强制写入限速寄存器 (`PA31`) |
| **SYS_RUNNING** | 闭环运行 | 监控指令变化，按 Delta > 阈值进行变动下发 |

---

## 4. 关键文件索引

- **[servo_manager.h](file:///d:/Software/antigravity/esp32_sorter/src/servo_manager.h)**: 定义了状态枚举与核心调度接口。
- **[servo_control_handler.h](file:///d:/Software/antigravity/esp32_sorter/src/servo_control_handler.h)**: 定义了不同控制类型（Knob/Pot/Torque）的 UI 逻辑。
- **[modbus_controller.cpp](file:///d:/Software/antigravity/esp32_sorter/src/modbus_controller.cpp)**: 实现了 CRC16 与同步/异步读写时序。

---
*此文档致力于协助开发者快速理解伺服控制的设计哲学。如有修改，请同步更新 `Software_Architecture.md`。*

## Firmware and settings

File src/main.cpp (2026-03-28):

#include <Arduino.h>
#include <EEPROM.h>
#include <Wire.h>

#include "main.h"
#include "config.h"
#include "user_interface/user_interface.h"
#include "user_interface/oled.h"
#include "user_interface/terminal.h"
#include "user_interface/menu_system.h"
#include "modular/encoder.h"
#include "modular/sorter.h"
#include "handlers/scanner_diagnostic_handler.h"
#include "handlers/outlet_diagnostic_handler.h"
#include "handlers/encoder_diagnostic_handler.h"
#include "handlers/config_handler.h"
#include "handlers/hmi_diagnostic_handler.h"

#include "system/menu_config.h"
#include "system/system_manager.h"
#include "system/mode_processors.h"

// =========================
// 单例实例
// =========================
UserInterface* userInterface = UserInterface::getInstance();
Encoder* encoder = Encoder::getInstance();
DiameterScanner* diameterScanner = DiameterScanner::getInstance();
TraySystem* traySystem = TraySystem::getInstance();
Sorter sorter;

// 诊断处理器
ScannerDiagnosticHandler scannerDiagnosticHandler;
OutletDiagnosticHandler outletDiagnosticHandler;
EncoderDiagnosticHandler encoderDiagnosticHandler;
HMIDiagnosticHandler hmiDiagnosticHandler(UserInterface::getInstance());
DiameterConfigHandler diameterConfigHandler(userInterface, &sorter);
PhaseOffsetConfigHandler phaseOffsetConfigHandler(userInterface, &sorter);

int normalModeSubmode = 0;
bool hasVersionInfoDisplayed = false;
String systemName = "Feng's AS-L9";

// FreeRTOS 任务句柄
TaskHandle_t hControlTask = nullptr;
TaskHandle_t hUITask = nullptr;

// 任务函数声明
void vControlTask(void* pvParameters);
void vUITask(void* pvParameters);

void setup() {
    Serial.begin(115200);
    Serial.println("Feng's Sorter system starting...");
    
    userInterface->initialize();
    OLED::getInstance()->initialize();
    Terminal::getInstance()->initialize();
    
    // 注入显示设备
    UserInterface::addExternalDisplayDevice(OLED::getInstance());
    UserInterface::addExternalDisplayDevice(Terminal::getInstance());
    
    userInterface->enableOutputChannel(OUTPUT_ALL);
    
    delay(500);
    
    for (uint8_t i = 0; i < NUM_OUTLETS; i++) {
        outletDiagnosticHandler.setOutlet(i, sorter.getOutlet(i));
    }
    
    EEPROM.begin(512);
    EEPROM.get(EEPROM_ADDR_BOOT_COUNT, systemBootCount);
    if (systemBootCount == 0xFFFFFFFF) systemBootCount = 0;
    systemBootCount++;
    EEPROM.put(EEPROM_ADDR_BOOT_COUNT, systemBootCount);
    EEPROM.commit();
    
    encoder->initialize();

    // 开机从 EEPROM 加载 phaseOffset（带 magic 校验）
    uint8_t phaseOffsetMagic  = EEPROM.read(EEPROM_ADDR_PHASE_OFFSET);
    uint8_t phaseOffsetValue  = EEPROM.read(EEPROM_ADDR_PHASE_OFFSET + 1);
    Serial.printf("[BOOT] EEPROM raw: magic=0x%02X value=%d\n", phaseOffsetMagic, phaseOffsetValue);
    uint8_t savedOffset = 0;
    if (phaseOffsetMagic == 0xA5 && phaseOffsetValue < ENCODER_MAX_PHASE) {
        savedOffset = phaseOffsetValue;
    }
    encoder->setPhaseOffset(savedOffset);
    Serial.printf("[BOOT] Phase offset applied: %d\n", savedOffset);

    sorter.initialize();
    diameterScanner->initialize();
    traySystem->loadFromEEPROM(EEPROM_ADDR_TRAY_DATA);
    
    outletDiagnosticHandler.initialize(userInterface);
    encoderDiagnosticHandler.initialize(userInterface);
    
    setupMenuTree();
    Serial.println("System ready");

    // ==========================================
    // 任务创建：将分拣控制核心与 UI 交互核心物理隔离
    // ==========================================
    
    // 1. 创建控制任务 (Core 1, 高优先级, 1000Hz)
    xTaskCreatePinnedToCore(
        vControlTask,   // 任务函数
        "ControlTask",  // 任务名称
        4096,           // 栈大小
        nullptr,        // 参数
        10,             // 优先级 (最高)
        &hControlTask,  // 句柄
        1               // 绑定到 Core 1 (Arduino 默认核)
    );

    // 2. 创建 UI 任务 (Core 0, 低优先级, 30Hz)
    xTaskCreatePinnedToCore(
        vUITask,        // 任务函数
        "UITask",       // 任务名称
        8192,           // 栈大小
        nullptr,        // 参数
        1,              // 优先级
        &hUITask,       // 句柄
        0               // 绑定到 Core 0
    );
}

void vControlTask(void* pvParameters) {
    TickType_t xLastWakeTime = xTaskGetTickCount();
    const TickType_t xFrequency = pdMS_TO_TICKS(1); // 1ms 循环频率

    Serial.println("[FreeRTOS] ControlTask (Core 1) started.");

    for (;;) {
        // 分拣逻辑消费执行
        // 只有在 Normal 模式或特定的分拣诊断模式下才运行逻辑处理槽
        if (currentMode == MODE_NORMAL || currentMode == MODE_DIAGNOSE_OUTLET || currentMode == MODE_DIAGNOSE_SCANNER) {
            sorter.run();
        }
        
        // 保持 1ms 的确定性节拍
        vTaskDelayUntil(&xLastWakeTime, xFrequency);
    }
}

void vUITask(void* pvParameters) {
    Serial.println("[FreeRTOS] UITask (Core 0) started.");

    for (;;) {
        int delta = userInterface->getEncoderDelta();
        bool btnPressed = userInterface->isMasterButtonPressed();
        uint32_t currentMs = millis();
        
        if (menuModeActive) {
            bool needsRefresh = false;
            if (delta != 0) {
                menuSystem.handleInput(delta, false);
                needsRefresh = true;
            }
            if (btnPressed) {
                menuSystem.handleInput(0, true);
                if (menuModeActive) needsRefresh = true;
            }
            if (needsRefresh) {
                userInterface->renderMenu(menuSystem.getCurrentNode(), menuSystem.getCursorIndex(), menuSystem.getScrollOffset());
            }
        } else {
            handleModeChange(); // 强制模式状态检查

            // 处理工作模式逻辑 (主要由 Handler 更新显示)
            if (activeHandler) {
                activeHandler->update(currentMs, btnPressed);
                
                // 模式特定的附加补丁
                if (currentMode == MODE_DIAGNOSE_OUTLET) {
                    if (delta != 0) {
                        outletDiagnosticHandler.handleEncoderInput(delta);
                    }
                }
            } else {
                if (btnPressed) {
                    handleReturnToMenu();
                } else {
                    switch (currentMode) {
                        case MODE_NORMAL:
                            if (delta != 0) normalModeSubmode = (normalModeSubmode + 1) % 2;
                            processNormalMode();
                            break;
                        case MODE_VERSION_INFO:
                            processVersionInfoMode();
                            break;
                        default:
                            break;
                    }
                }
            }
        }
        
        // 给系统任务（如 Watchdog/WiFi）留出时间，并维持约 30Hz 刷新
        vTaskDelay(pdMS_TO_TICKS(30));
    }
}

// ==========================================
// Arduino 框架要求
// ==========================================
void loop() {
    // 原始 loop() 在双核模式下已废弃，任务由 vControlTask 和 vUITask 承载
    // 我们直接删除这个默认创建的 IDLE 任务以节省资源
    vTaskDelete(NULL);
}


//  测量直径很稳定的版本了

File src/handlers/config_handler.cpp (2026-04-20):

#include "config_handler.h"

// =========================
// DiameterConfigHandler实现
// =========================

void DiameterConfigHandler::initializeMode() {
  currentSubMode = 0; 
  uiState = STATE_SELECTOR;
  encoderAccumulator = 0; // 初始化分频累加器
  refreshDisplay();
}

void DiameterConfigHandler::update(uint32_t currentMs, bool btnPressed) {
    // 1. 处理旋钮输入 (2:1 平和分频)
    int rawDelta = userInterface->getRawEncoderDelta();
    if (rawDelta != 0) {
        encoderAccumulator += rawDelta;
        if (abs(encoderAccumulator) >= 2) {
            int logicalDelta = encoderAccumulator / 2;
            encoderAccumulator %= 2; 
            handleValueChange(logicalDelta);
        }
    }
    
    // 2. 自愈刷新
    if (currentMs - lastRefreshMs >= 250) { 
        lastRefreshMs = currentMs;
        refreshDisplay();
    }

    // 3. 处理按键动作: 列表 -> 改大 -> 改小 -> 改长 -> 列表
    if (btnPressed) {
      lastRefreshMs = currentMs;
      
      if (uiState == STATE_SELECTOR) {
          if (currentSubMode == 0) {
              uint8_t m = sorter->getOutlet0Mode();
              sorter->setOutlet0Mode(m == 0 ? 1 : 0);
          } else if (currentSubMode == NUM_OUTLETS + 1) {
              sorter->saveConfig(); 
              handleReturnToMenu();
              return; 
          } else {
              uiState = STATE_EDIT_MAX;
          }
      } else if (uiState == STATE_EDIT_MAX) {
          uiState = STATE_EDIT_MIN;
      } else if (uiState == STATE_EDIT_MIN) {
          uiState = STATE_EDIT_LENGTH;
      } else if (uiState == STATE_EDIT_LENGTH) {
          uiState = STATE_SELECTOR;
      }
      refreshDisplay();
    }
}

void DiameterConfigHandler::refreshDisplay() {
  // 3-bit: S(bit0), M(bit1), L(bit2). 0: invalid, 1-7: valid combinations.
  
  if (uiState == STATE_SELECTOR) {
      String listContent = "";
      int totalItems = NUM_OUTLETS + 2;
      int startIdx = max(0, currentSubMode - 1);
      int endIdx = min(totalItems, startIdx + 4); 
      if (endIdx - startIdx < 4) startIdx = max(0, endIdx - 4);

      for (int i = startIdx; i < endIdx; i++) {
          if (i == currentSubMode) listContent += "> ";
          else listContent += "  ";

          if (i == 0) {
              String modeStr = (sorter->getOutlet0Mode() == 0) ? "MUL-OBJ" : "DIAMETER";
              listContent += "O1 MODE: [" + modeStr + "]\n";
          } else if (i <= NUM_OUTLETS) {
              int outletIdx = i - 1;
              int minV = sorter->getOutletMinDiameter(outletIdx);
              int maxV = sorter->getOutletMaxDiameter(outletIdx);
              uint8_t targetL = sorter->getOutlet(outletIdx)->getTargetLength();
              
              bool isValid = true;
              if (minV >= maxV && outletIdx > 0) isValid = false;
              if (outletIdx > 1) {
                  int prevMin = sorter->getOutletMinDiameter(outletIdx - 1);
                  if (maxV > prevMin) isValid = false;
              }
              /* 
              if (!isValid && i != currentSubMode) {
                  // 规则有变，暂不显示感叹号
                  listContent.remove(listContent.length() - 2);
                  listContent += "! ";
              }
              */
              // 生成显式状态字符串，例如 "[S M  ]", "[  M L]", "[S M L]"
              String modeStr = "[";
              modeStr += (targetL & LEN_S) ? "S " : "  ";
              modeStr += (targetL & LEN_M) ? "M " : "  ";
              modeStr += (targetL & LEN_L) ? "L" : " ";
              modeStr += "]";
              
              listContent += "O" + String(outletIdx + 1) + ": " + 
                             String(minV) + "-" + String(maxV) + " " + modeStr + "\n";
          } else {
              listContent += "[ SAVE & EXIT ]\n";
          }
      }
      userInterface->displayDiagnosticInfo("DIAMETER/LEN CONFIG", listContent);
      
  } else {
      int outletIdx = currentSubMode - 1;
      String title = "OUTLET " + String(outletIdx + 1) + " SETUP";
      int minV = sorter->getOutletMinDiameter(outletIdx);
      int maxV = sorter->getOutletMaxDiameter(outletIdx);
      uint8_t targetL = sorter->getOutlet(outletIdx)->getTargetLength();
      
      int activeField = (uiState == STATE_EDIT_MAX) ? 0 : 
                        (uiState == STATE_EDIT_MIN) ? 1 : 2;
      
      userInterface->displayConfigEdit(title, maxV, minV, targetL, activeField);
  }
}
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

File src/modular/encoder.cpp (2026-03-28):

#include "encoder.h"
#include "../config.h"

// 静态成员初始化
// Encoder* Encoder::instance = nullptr; // Managed by Singleton template

// 编码器逻辑位置范围常量
const int ENCODER_LOGICAL_POSITION_RANGE = ENCODER_MAX_PHASE;

/**
 * 私有构造函数 - 单例模式
 */
Encoder::Encoder() {
    rawEncoderCount = 0;
    lastEncoderCount = 0;
    zeroCrossCount = 0;
    zeroCrossRawCount = 0;
    forcedZeroCount = 0;
    forcedZeroRawCount = 0;
    phaseOffset = 0;  // 默认无偏移，装机标定后可修改
    
    // 初始化回调函数指针为nullptr
    encoderPhaseCallback = nullptr;
    encoderPhaseCallbackContext = nullptr;

    // 初始化状态缓存
    pinA_state = LOW;
    pinB_state = LOW;
}

/**
 * 获取单例实例的静态方法 - Managed by Singleton template
 */
// Encoder* Encoder::getInstance() { ... }

/**
 * 初始化编码器引脚和中断
 */
void Encoder::initialize() {
    // 配置编码器A相、B相、Z相引脚为输入模式
    pinMode(PIN_ENCODER_A, INPUT_PULLUP);
    pinMode(PIN_ENCODER_B, INPUT_PULLUP);
    pinMode(PIN_ENCODER_Z, INPUT_PULLUP);
    
    // 配置外部中断处理函数（双中断模式）
    attachInterrupt(digitalPinToInterrupt(PIN_ENCODER_A), handleAPhaseInterrupt, CHANGE);
    attachInterrupt(digitalPinToInterrupt(PIN_ENCODER_B), handleBPhaseInterrupt, CHANGE);
    attachInterrupt(digitalPinToInterrupt(PIN_ENCODER_Z), handleZPhaseInterrupt, FALLING);
    
    // 初始化内部状态变量并同步初始引脚电平
    rawEncoderCount = 0;
    lastEncoderCount = 0;
    zeroCrossCount = 0;
    zeroCrossRawCount = 0;
    forcedZeroCount = 0;
    forcedZeroRawCount = 0;
    
    pinA_state = digitalRead(PIN_ENCODER_A);
    pinB_state = digitalRead(PIN_ENCODER_B);
}

/**
 * 获取当前逻辑位置（0-199）
 */
int Encoder::getCurrentPosition() {
    int position = rawEncoderCount % ENCODER_LOGICAL_POSITION_RANGE;
    if (position < 0) {
        position += ENCODER_LOGICAL_POSITION_RANGE;
    }
    // 叠加零位偏移量，补偿各机器编码器安装位置差异
    return (position + phaseOffset) % ENCODER_LOGICAL_POSITION_RANGE;
}

/**
 * 设置相位回调
 */
void Encoder::setPhaseCallback(void* context, PhaseCallback callback) {
    encoderPhaseCallback = callback;
    encoderPhaseCallbackContext = context;
}

/**
 * A相中断处理函数
 */
void Encoder::handleAPhaseInterrupt() {
    Encoder* enc = getInstance();
    int A = digitalRead(PIN_ENCODER_A);
    if (A != enc->pinA_state) {
        int dN = (A == enc->pinB_state) ? 1 : -1;
        if (ENCODER_REVERSE_DIRECTION) {
            enc->rawEncoderCount -= dN;
        } else {
            enc->rawEncoderCount += dN;
        }
        enc->pinA_state = A;
        enc->triggerPhaseCallback();
    }
}

/**
 * B相中断处理函数
 */
void Encoder::handleBPhaseInterrupt() {
    Encoder* enc = getInstance();
    int B = digitalRead(PIN_ENCODER_B);
    if (B != enc->pinB_state) {
        int dN = (enc->pinA_state != B) ? 1 : -1;
        if (ENCODER_REVERSE_DIRECTION) {
            enc->rawEncoderCount -= dN;
        } else {
            enc->rawEncoderCount += dN;
        }
        enc->pinB_state = B;
        enc->triggerPhaseCallback();
    }
}

/**
 * Z相中断处理函数
 */
void Encoder::handleZPhaseInterrupt() {
    // if (!instance) return;
    Encoder* enc = getInstance();
    
    // 增加清零次数计数
    enc->zeroCrossCount++;
    
    // 记录Z相触发时的原始计数值
    enc->zeroCrossRawCount = enc->rawEncoderCount;
    
    // 当清零时，如果计数器对400取模余数不是0，则强行设为0
    if (enc->rawEncoderCount % 400 != 0) {
        // 记录强制清零时的原始计数值
        enc->forcedZeroRawCount = enc->rawEncoderCount;
        // 增加强制清零计数
        enc->forcedZeroCount++;
        // 直接设为0
        enc->rawEncoderCount = 0;
    }
    
    // 调用触发相位回调的方法，传递特殊相位值255表示Z相信号
    if (enc->encoderPhaseCallback != nullptr) {
        enc->encoderPhaseCallback(enc->encoderPhaseCallbackContext, 255);
    }
}

/**
 * 私有方法：触发相位回调
 * 避免代码重复，在A相、B相和Z相中断处理中被调用
 */
void Encoder::triggerPhaseCallback() {
    if (encoderPhaseCallback != nullptr) {
        int raw = rawEncoderCount % ENCODER_LOGICAL_POSITION_RANGE;
        if (raw < 0) raw += ENCODER_LOGICAL_POSITION_RANGE;
        int currentPhase = (raw + phaseOffset) % ENCODER_LOGICAL_POSITION_RANGE;
        encoderPhaseCallback(encoderPhaseCallbackContext, currentPhase);
    }
}

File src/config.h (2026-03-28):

#ifndef CONFIG_H
#define CONFIG_H

#include <Arduino.h>

// ==========================================
// System Information
// ==========================================
constexpr const char* SYSTEM_NAME = "ESP32 Sorter";
constexpr const char* FIRMWARE_VERSION = "2.0.0";

// ==========================================
// Pin Definitions
// ==========================================

// 级联 74HC595 移位寄存器引脚 (控制指示 LED 与 Solenoids H-Bridge)
constexpr int PIN_HC595_DS   = 33;  // 数据输入
constexpr int PIN_HC595_SHCP = 4;   // 移位脉冲
constexpr int PIN_HC595_STCP = 2;   // 锁存脉冲

// HMI Module (Rotary Encoder with Push Button)
constexpr int PIN_HMI_ENC_A = 13;
constexpr int PIN_HMI_ENC_B = 12;
constexpr int PIN_HMI_BTN   = 14;

// Power Monitor (Voltage Divider Input)
constexpr int PIN_POWER_MONITOR = 32;

// Scanner (5 Points Array)
constexpr int PIN_SCANNER_1 = 36;
constexpr int PIN_SCANNER_2 = 39;
constexpr int PIN_SCANNER_3 = 34;
constexpr int PIN_SCANNER_4 = 35;
constexpr int PIN_SCANNER_5 = 15;

// Main Encoder
constexpr int PIN_ENCODER_A = 19;
constexpr int PIN_ENCODER_B = 21;
constexpr int PIN_ENCODER_Z = 18;

// Display (I2C)
constexpr int PIN_OLED_SDA = 23;
constexpr int PIN_OLED_SCL = 22;

// Hardware Serial 0 (Debug)
constexpr int PIN_UART0_TX = 1;
constexpr int PIN_UART0_RX = 3;


constexpr int PINS_SCANNER[5] = {
    PIN_SCANNER_1, PIN_SCANNER_2, PIN_SCANNER_3, PIN_SCANNER_4, PIN_SCANNER_5
};

// ==========================================
// Hardware Constants
// ==========================================

// Encoder / Conveyor
constexpr int ENCODER_MAX_PHASE = 200;
constexpr int PULSES_PER_TRAY = 200;
constexpr bool ENCODER_REVERSE_DIRECTION = false; // 软件反转编码器计数方向

// Output
constexpr int NUM_OUTLETS = 8;

// Scanner: 托盘 pitch 为 101.6mm，逻辑周期为 200 phase，故物理权重为 101.6/200 = 0.508
constexpr float SCANNER_WEIGHTS[4] = {0.508f, 0.508f, 0.508f, 0.508f};
constexpr int SCANNER_MIN_DIAMETER_UNIT = 5; // 约 2.5mm

// ==========================================
// Timing & Phases
// ==========================================

// Critical Encoder Phases (核心分拣时序相位, 0-199 循环)
// 系统通过编码器追踪物体在分拣流水线上的物理位置，每个循环代表一个托架间隔 (Pitch)

// 1. 启动扫描阶段：托盘进入传感器正下方，直径扫描仪开始记录脉冲宽度
constexpr int PHASE_SCAN_START = 50;

// 2. 数据锁存阶段：物体离开传感器，停止统计脉冲并在此刻计算直径值，推入托盘系统
constexpr int PHASE_DATA_LATCH = PHASE_SCAN_START + 120;  //170

// 3. 执行分级阶段：根据锁存的直径，在流水线出口处匹配对应的分拣仓位，触发电磁铁翻转动作
constexpr int PHASE_OUTLET_EXECUTE = PHASE_SCAN_START - 20;

// 4. 重置归位阶段：在当前托架周期结束前，重置出口控制信号位，清理中间计算标志位，准备下一轮
constexpr int PHASE_OUTLET_RESET = 150;

// ==========================================
// Sorting Logic Constants
// ==========================================
enum LengthMask {
    LEN_NONE = 0x00,
    LEN_S    = 0x01, // 1 << 0
    LEN_M    = 0x02, // 1 << 1
    LEN_L    = 0x04, // 1 << 2
    LEN_ALL  = 0x07  // S | M | L
};



// ==========================================
// EEPROM Addresses
// ==========================================
// Layout: [0x00] Diameter  [0x64] BootCount  [0x70] TrayData  [0x110] PhaseOffset
// TraySystem writes: magic(1) + 18*int*2 = 145 bytes => 0x70..0x100
constexpr int EEPROM_ADDR_DIAMETER       = 0x00; // 1 byte:  magic marker (0xAA = initialized)
constexpr int EEPROM_ADDR_DIAMETER_DATA  = 0x01; // 24 bytes: NUM_OUTLETS * 3 (min, max, length)
constexpr int EEPROM_ADDR_OUTLET0_MODE   = 0x19; // 1 byte:  outlet 0 mode (0=multi-obj, 1=diameter)
constexpr int EEPROM_ADDR_BOOT_COUNT     = 0x64; // 4 bytes: uint32 boot counter
constexpr int EEPROM_ADDR_TRAY_DATA      = 0x70; // 145 bytes: magic + 18*(diameter+count) ints => ends at 0x100
constexpr int EEPROM_ADDR_PHASE_OFFSET   = 0x110; // 2 bytes: [0]=magic(0xA5), [1]=offset value

// Power Loss Threshold (ADC value: 0-4095)
constexpr int POWER_LOSS_ADC_THRESHOLD = 3000;

// 脉冲宽度配置 (单位：ms) - 硬编码方案
constexpr int PULSE_OPEN_MS  = 100;
constexpr int PULSE_CLOSE_MS = 300;

#endif // CONFIG_H

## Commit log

2025-10-29 ESP32 Sorter 项目完成基础编码器模块开发，包含encoder_module.cpp和encoder_module.h文件的实现。
2025-10-30 完成ESP32分拣系统核心功能实现，包括托架管理、分支器控制和物料分拣算法
2025-10-30 删除旧文件：main.c、CMakeLists.txt和encoder_module.h
2025-10-30 删除旧文件：encoder_module.cpp
2025-10-30 更新硬件描述文档
2025-10-30 更新.gitignore文件，添加缓存目录和构建输出忽略规则
2025-10-30 更新项目规则文档
2025-10-30 修复platformio.ini配置：将include_dir改为正确的include_dirs选项
2025-10-30 改进系统工作模式：将布尔testMode替换为支持多种调试模式的enum类型
2025-10-30 修复代码结构问题，正确实现诊断器硬件功能
2025-10-30 重构诊断器系统：创建pins.h统一管理引脚，封装诊断器功能到DiagnosticController类
2025-11-01 更新舵机引脚配置和项目文件结构
2025-11-02 清理无用代码并优化项目结构
2025-11-02 完成Outlet类最小最大直径功能实现，移除无效update方法，修复编译错误
2025-11-03 更新所有文档，修正模糊和二义性描述，添加更详细的功能说明
2025-11-03 清理未使用代码：移除DiameterScanner中未使用的SAMPLE_BUFFER_SIZE常量和TraySystem中未被调用的getInvalidDiameter()方法
2025-11-03 更新文档和优化代码格式：移除diameter_scanner.md中的错误缓冲区说明，更新encoder.md、simple_hmi.md文档，创建sorter.md文档，清理main.cpp未使用变量，优化sorter.cpp和sorter.h的代码格式
2025-11-03 清理代码和文档：移除未使用代码，修复文档模糊描述，更新中断处理机制
2025-11-04 优化代码：移除未使用的displayTrayQueue()方法，提高代码整洁度
2025-12-11 Update scanner functionality and fix pin definitions
    [diameter_scanner.cpp, main.cpp, oled.cpp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]
2026-01-11 将MODE_BUTTON_PIN从GPIO 0改为GPIO 4
2026-01-18 完成代码优化和重构： 1. 重构托盘系统为AsparagusTrayManager 2. 添加诊断处理类（ScannerDiagnosticHandler、OutletDiagnosticHandler等） 3. 优化直径扫描仪，移除日志功能 4. 更新编码器实现，添加AB相双中断模式 5. 优化分拣速度方法，合并为getSortingSpeedPerSecond() 6. 重命名trayCou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
    [asparagus_tray_manager.cpp, diameter_scanner.cpp, encoder.cpp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]
2026-01-19 完成OLED类重构和DisplayData相关类的移除\n\n1. 重构OLED类，从模式专用方法转变为功能专用方法\n2. 移除DisplayDataGenerator类和相关文件\n3. 从Sorter类中移除getDisplayData方法\n4. 更新UserInterface类，添加输出控制功能\n5. 添加语言选择功能，支持中英文切换\n6. 实现统一的输出方法\n7. 移除过时的A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
    [encoder.cpp, main.cpp, oled.cpp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]
2026-01-19 重构项目结构：将模块文件移动到modular目录，UI文件移动到user_interface目录
2026-01-19 完成项目结构重构并清理临时文件
2026-01-19 重构OutletDiagnosticHandler类： 1. 将processCycleDrop/Raise函数内联到update方法 2. 删除未使用的垃圾函数（getOutletCount等） 3. 移除LED控制代码（硬件不存在） 4. 重构Outlet对象访问方式，降低耦合度 5. 内联setOutletState方法，移除不必要的安全检查
2026-01-20 Fix startup mode issue and improve terminal display system
    [encoder.cpp, main.cpp, oled.cpp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]
2026-01-24 Refactor encoder diagnostic functionality and clean up display logic
2026-01-26 Cleanup: Remove unused LED and reloader functionality, fix enum values, and update documentation
    [config_handler.cpp, config_handler.h, encoder_diagnostic_handler.cpp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]
2026-01-26 Adjust tray queue capacity from 31 to 19 (0-18) as requested
2026-02-01 Backup: Reverted solenoid changes and saved current state
    [config.h, config_handler.h, diameter_scanner.cpp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]
2026-02-22 feat(hmi): optimize encoder logic and fix UI refresh/inversion issues
    [config.h, config_handler.cpp, config_handler.h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]
2026-02-22 feat: Implement initial ESP32 sorter system with modular components, comprehensive hardware configuration, and diagnostic handlers.
2026-03-06 Refactor: Modularize main.cpp, implement ModbusController C++ class, and optimize servo control
2026-03-17 feat: implement HMI encoder diagnostic mode and optimize pulse decoding
    - Added HMIDiagnosticHandler for real-time pulse monitoring- Refactored SimpleHMI to use a non-consuming global pulse counter- Implemented 1:4 logical sensitivity to match physical detents- Optimized ISR with gpio_get_level and noise detection (Err counter)- Fixed pulse loss bug by decoupling menu and diagnostic consumers- Updated Diagnostics menu with HMI Encoder option
    [main.cpp, menu_config.cpp, mode_processors.cpp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]
2026-03-18 refactor: clean up test LED logic and encapsulate potentiometer speed control
2026-03-20 feat: integrate industrial standard 9-state servo machine and SRP refactor
2026-03-20 perf: replace blocking Modbus read with async request-poll pattern
    [modbus_controller.cpp, mode_processors.cpp, servo_manager.cpp]
2026-03-20 perf: remove blocking delays from main loop hot paths (oled safeDisplay, servo monitor)
2026-03-20 perf(P1): implement Modbus bus arbitration and full-async ServoMonitorHandler
    - ModbusController: writeRegister() now buffers into single-slot queue when
    a read is in-flight (_rxPending=true); write executes immediately after
    pollReadResult() completes, ensuring strict read/write bus exclusion
    - ServoMonitorData: added phaseCurrent (0x1008) and busVoltage (0x1012)
    - ServoManager::updateMonitor(): extended from 5 to 7-register async cycle
    - ServoMonitorHandler: completely rewritten to use ServoManager::getData()
    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
2026-03-22 servo manual
2026-03-22 laser diag menu is ok
2026-03-22 出口位置
2026-03-22 不对称脉冲时间
2026-03-23 优化 Dashboard
2026-03-23 测量直径很稳定的版本
2026-03-25 统计正确了
2026-03-27 encoder offset
2026-03-28 五项重构
2026-04-10 servo driver
